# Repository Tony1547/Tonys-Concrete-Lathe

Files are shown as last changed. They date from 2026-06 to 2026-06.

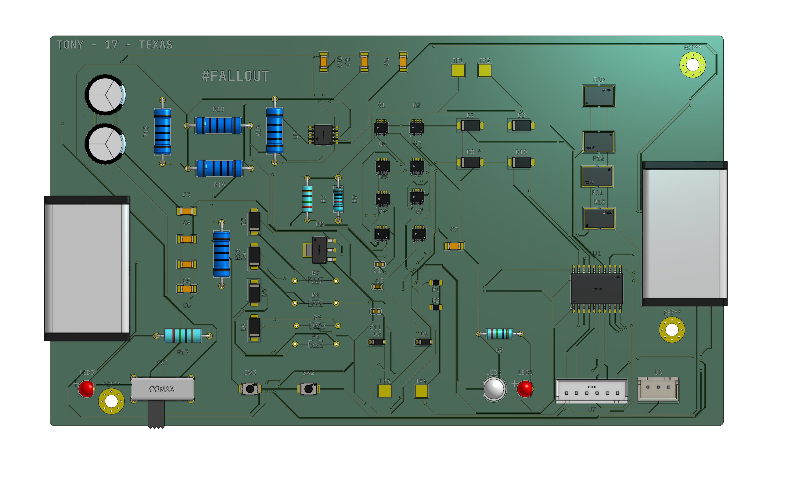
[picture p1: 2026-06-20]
images/LathePCB.png

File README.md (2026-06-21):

# Tonys-Concrete-Lathe #
Lathe but 3d prints &amp; concrete



Special thanks Mark Harris to for creating this open source design which I based my H-brdge motor driver off of, heres the link to his blog of his design and his git hub page:

- https://resources.altium.com/p/100a-12v-h-bridge-project

- https://github.com/issus

and another big thanks to Chris Borge for inspiring this project with his "I Printed A Better Lathe" video

- https://www.youtube.com/watch?v=6Js8erWbsDQ

---- 



This is the lathe I have been desingning for the past 2-ish months, I was initially inspired by Chris Borge a Youtuber who focuses on creating machines to help with his own personal projects and 3d-prints that are filled with concrete. Now, this is the second iteration design, not becuase I built a first lathe but because the first time I tried to put everything into CAD it all started to look like a toy and I thought I could do better, which I'm glad that I did. Which now leads to the vesion you see above and below this bar of text.

Something I initially struggled with was finding a way to connect all the parts toghether, in my initial design I tried to make each 3d printed part interlock with dove-tails but that soon became much more problematic than was needed. I solved this problem with allowing an open hole from part to part on the inside to connect all parts into this chamber that I hope keeps everything together once the concrete dries. 

For the reason that I built this project, I want to have better manufacturing capabilities at home, and having a machine that allows me to focus on one type of part (being conical and cylindrical parts) I think will allow me to have better projects in the future.

Journal: https://fallout.hackclub.com/projects/1831



# Assembly
Hi! if you're reading this, your either reading to review, see whats going on, or interested in building this project yourself.

- The first step in creating the lathe is set up, make sure you have all hardware, bearings, belt &amp; pulley's, 3d prints, PCB, concrete, and extrusion material on hand

- Make sure to use heated inserts before this next step and to cover anny holes which may clog with concrete with tape.

- The next step is is to assemble the base, head stock, and upper walls seperately, glue them with each other inside those groups and let it rest (you may want to put the hardware, extrusions, and linear slide in for the base before glueing), after the glue is done drying, you may start off by pouring concrete into the base.

- After concrete has been poured into the base (process can change depending on the part) you can now assemble and put-in the top of the lathe wall and headstock and fill those with conctete as well, if you can find a power tool to vibrate the lathe to allow air bubbles to escape then use that as well too.

-After allowing the concrete to dry, you may add on the tool carriage and screw on the PCB to to the lathe, make sure to wire and test and you should have a functional lathe!

Remember when using the lathe, the part should be spining to where it's coming down onto the tool and not the other way around.

Currently the lathe is run by either two buttons on the back for foward/revevrse but the option for external control was also given, so with an off board micro controller you could be very exact with how you want this thing to spin. (I plan to use an off board MCU when possible)





Onshape: https://cad.onshape.com/documents/8fec9f06f8e21e4e1cabcead/w/11b83efad18e13bc0ea2df61/e/2ea9e03e0bad05dbdf986923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

# BOM

Google Sheet: https://docs.google.com/spreadsheets/d/1Rf3SECQ2E7oCPYBzGCeOMEVJCDXd7yVN8Rsrsj5uyMo/edit?usp=sharing 

| Index | Vendor | Description | Quantity | Unit Price($) | Extended Price($) | Product Link | | | | | | | |
|---|---|---|---|---|---|---|---|---|-----|---|---|---|---|
| 1 | Ali Express | 5x13x4mm Flanged Bearing | 10 | $0.51 | $5.06 | https://www.aliexpress.us/item/3256803908686248.html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 | | | | | | | |
| 2 | Ali Express | 140T GT2 10mm belt | 1 | $3.78 | $3.78 | https://www.aliexpress.us/item/3256806906134014.html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 | | | | | | | |
| 3 | Ali Express | ER25 8mm Collet | 1 | $6.25 | $6.25 | https://www.aliexpress.us/item/2255800773550976.html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 | | | | | | | |
| 4 | Ali Express | 50mm Chuck | 1 | $20.01 | $20.01 | https://www.aliexpress.us/item/3256809251348831.html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 | | | | | | | |
| 5 | Ali Express | 30T + 60T Pulley's | 2 | $9.47 | $18.94 | https://www.aliexpress.us/item/3256805897449052.html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 | | | | | | | |
| 6 | Ali Express | 20x47x19.25 Tapered Roller Bearing | 2 | $3.59 | $7.18 | https://www.aliexpress.us/item/3256802472132854.html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 | | | | | | | |
| 7 | Ali Express | C20-ER25-150L Spindle | 1 | $15.84 | $15.84 | https://www.aliexpress.us/item/3256801168631119.html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 | | | | | | | |
| 8 | Tnutz | 2020 Extrusion | 2 | $1.33 | $2.66 | https://www.tnutz.com/product/exm-2020/?attribute_pa_length-in=12&attribute_pa_fractional-length=0-000 | | | | | | | |
| 9 | Tnutz | Tapped 2020 Extrusion | 2 | $0.77 | $1.54 | https://www.tnutz.com/product/exm-2020/?attribute_pa_length-in=3&attribute_pa_fractional-length=0-938-15-16 | | | | | | | |
| 10 | Tnutz | M3 T-Nut | 40 | $0.40 | $16.00 | https://www.tnutz.com/product/st-020/?attribute_pa_thread-size=m3-x-0-5 | | | | | | | |
| 11 | Grainger | 1M M4 Threaded Rod | 1 | $2.35 | $2.35 | https://www.grainger.com/product/Fully-Threaded-Rod-M4x0-70-25DM24 | | | | | | | |
| 12 | Grainger | M4 Nuts | 100 | $0.03 | $2.94 | https://www.grainger.com/product/Hex-Nut-Std-Hex-6CA71 | | | | | | | |
| 13 | Amazon | M3 Nuts | 150 | $0.03 | $4.99 | https://www.amazon.com/gp/product/B08N68W9SP/ref=ox_sc_act_title_1?smid=A2BPIUS9TNF8L5&psc=1 | | | | | | | |
| 14 | Amazon | 2 Part Epoxy | 1 | $5.97 | $5.97 | https://www.amazon.com/gp/product/B001Z3C3AG/ref=ox_sc_act_title_2?smid=ATVPDKIKX0DER&psc=1 | | | | | | | |
| 15 | Amazon | M3 Brass Inserts | 100 | $0.05 | $4.99 | https://www.amazon.com/gp/product/B0FM45X5TD/ref=ox_sc_act_title_3?smid=AIMQC13A5VC4X&psc=1 | | | | | | | |
| 16 | Amazon | M4 Brass Inserts | 60 | $0.08 | $4.83 | https://www.amazon.com/gp/product/B0DFWVT6XT/ref=ox_sc_act_title_4?smid=A3FX0IVQQTIB98&psc=1 | | | | | | | |
| 17 | Amazon | M3x10mm Screws | 120 | $0.03 | $3.79 | https://www.amazon.com/gp/product/B0F7LKRV5G/ref=ox_sc_act_title_5?smid=A2W3XYA7BVZZ2U&psc=1 | | | | | | | |
| 18 | Amazon | M3x25mm Screws | 40 | $0.16 | $6.39 | https://www.amazon.com/gp/product/B08R8J3175/ref=ox_sc_act_title_6?smid=A2XHUR0CG3X852&psc=1 | | | | | | | |
| 19 | Amazon | M3x22mm Screws | 50 | $0.13 | $6.29 | https://www.amazon.com/gp/product/B0FLYG7WZ7/ref=ox_sc_act_title_7?smid=A2SQCOYQC9C41K&psc=1 | | | | | | | |
| 20 | REV | #10-32 Socket head Screw | 50 | $0.11 | $5.50 | https://www.revrobotics.com/10-32-Socket-Head-Screws/ | | | | | | | |
| 21 | AndyMark | Cim Motor | 1 | $43.00 | $43.00 | https://andymark.com/products/2-5-in-cim-motor?variant=44497393680556 | | | | | | | |
| 22 | Ali Express | MGN9 300mm rail | 1 | $16.77 | $16.77 | https://www.aliexpress.us/item/2251832586981749.html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 | | | | | | | |
| 23 | Home Depot  | Concrete | 1 | $4.48 | $4.48 | https://www.homedepot.com/p/Quikrete-60-lb-Concrete-Mix-110160/100318478 | | | | | | | |
| | | | | Total = | $209.55 | | | | | | | | |
| | | | | | | | | | | | | | |
| Index | LCSC# | MPN | Manufacturer | Package | | Description | RoHS | Quantity | MOQ | Multiple | Unit Price($) | Extended Price($) | Product Link |
| 1 | C309795 | HIP4081AIBZT | RENESAS | SOIC-20-300mil | | Full-Bridge MOSFET 100mA 10ns 10ns 100mA SOIC-20-300mil Full Half-Bridge (H Bridge) Drivers RoHS | yes  | 1 | 1 | 1 | 4.3088 | 4.31 | https://www.lcsc.com/product-detail/C309795.html |
| 2 | C29936 | CL10B105KA8NNNC | Samsung Electro-Mechanics | 603 | | 1uF ±10% 25V Ceramic Capacitor X7R 0603 | yes  | 50 | 50  | 50 | 0.0219 | 1.1 | https://www.lcsc.com/product-detail/C29936.html |
| 3 | C22364900 | CDBA340L-G | Comchip | DO-214AC | | Diode 40V 3A Surface Mount DO-214AC | yes  | 8 | 1 | 1 | 1.1112 | 8.89 | https://www.lcsc.com/product-detail/C22364900.html |
| 4 | C18724377 | MF0S4FF200JA50 | UNI-ROYAL | Through Hole,D1.9xL3.3mm  | | 20Ω 250mW Metal Film Resistor ±50ppm/℃ ±1% Through Hole,D1.9xL3.3mm Through Hole Resistors RoHS | yes  | 50 | 50  | 50 | 0.005 | 0.25 | https://www.lcsc.com/product-detail/C18724377.html |
| 5 | C9807 | CL31A106KAHNNNE | Samsung Electro-Mechanics | 1206 | | 10uF ±10% 25V Ceramic Capacitor X5R 1206 | yes  | 10 | 10  | 10 | 0.0937 | 0.94 | https://www.lcsc.com/product-detail/C9807.html |
| 6 | C24497 | CL31B104KBCNNNC | Samsung Electro-Mechanics | 1206 | | 100nF ±10% 50V Ceramic Capacitor X7R 1206 | yes  | 20 | 20  | 20 | 0.019 | 0.38 | https://www.lcsc.com/product-detail/C24497.html |
| 7 | C553224 | PSMN1R5-25MLHX | Nexperia | SOT-1210 | | N-Channel 25V 150A 106W SOT-1210 | yes  | 8 | 1 | 1 | 3.6382 | 29.11 | https://www.lcsc.com/product-detail/C553224.html |
| 8 | C3454390 | MFR-25FBF52-2K2 | YAGEO | Through Hole,D2.4xL6.3mm  | | 2.2kΩ 250mW Metal Film Resistor ±100ppm/℃ ±1% Through Hole,D2.4xL6.3mm Through Hole Resistors RoHS | yes  | 50 | 50  | 50 | 0.0195 | 0.98 | https://www.lcsc.com/product-detail/C3454390.html  |
| 9 | C330747 | TJ-L3FYTGHKMCGSFLC7K-A5 | TOGIALED | Through Hole,D=3mm | | LED Indication - Discrete Through Hole,D=3mm | yes  | 20 | 20  | 20 | 0.0292 | 0.58 | https://www.lcsc.com/product-detail/C330747.html |
| 10 | C559114 | MHL5013UBDWT | MEIHUA | Through Hole,D=5mm | | Blue 470nm LED Indication - Discrete 3.2V Through Hole,D=5mm | yes  | 10 | 10  | 10 | 0.0523 | 0.52 | https://www.lcsc.com/product-detail/C559114.html |
| 11 | C61299 | CFR0W4J0103A50 | UNI-ROYAL | Through Hole,D2.2xL6.5mm  | | 10kΩ 250mW 250V Carbon Film Resistor ±450ppm/℃ ±5% Through Hole,D2.2xL6.5mm Through Hole Resistors RoHS | yes  | 50 | 50  | 50 | 0.0125 | 0.63 | https://www.lcsc.com/product-detail/C61299.html |
| 12 | C113892 | CC1206KKX7R0BB224 | YAGEO | 1206 | | 220nF ±10% 100V Ceramic Capacitor X7R 1206 | yes  | 20 | 20  | 20 | 0.0404 | 0.81 | https://www.lcsc.com/product-detail/C113892.html |
| 13 | C843877 | WSHP28182L000FEA | VISHAY | 2818 | | 2mΩ 10W ±1% ±200ppm/℃ 2818 Chip Resistor - Surface Mount RoHS | yes  | 4 | 1 | 1 | 2.3567 | 9.43 | https://www.lcsc.com/product-detail/C843877.html |
| 14 | C119483 | MF1W-1KΩ±1% T | CCO(Chian Chia Elec) | Through Hole,D4.5xL11.5mm | | 1kΩ 1W 350V Metal Film Resistor ±100ppm/℃ ±1% Through Hole,D4.5xL11.5mm Through Hole Resistors RoHS | yes  | 10 | 10  | 10 | 0.0496 | 0.5 | https://www.lcsc.com/product-detail/C119483.html |
| 15 | C707749 | KF88SA-16.0-2P | Cixi Kefa Elec | Through Hole,P=16mm | | 2 Position Barrier Block Connector 6~14 AWG 1000V 76A Through Hole | yes  | 2 | 1 | 1 | 0.8305 | 1.66 | https://www.lcsc.com/product-detail/C707749.html |
| 16 | C435835 | LDL1117S33R | ST | SOT-223-4 | | 3.3V Positive Fixed SOT-223-4 Voltage Regulators - Linear, Low Drop Out (LDO) Regulators RoHS | yes  | 5 | 5 | 5 | 0.2132 | 1.07 | https://www.lcsc.com/product-detail/C435835.html |
| 17 | C158012 | B2B-XH-A(LF)(SN) | JST | Through Hole,P=2.5mm | | Connector Header 2 position 2.5mm Pitch 3A Through Hole -25℃~+85℃ | yes  | 20 | 20  | 20 | 0.0405 | 0.81 | https://www.lcsc.com/product-detail/C158012.html |
| 18 | C144397 | B6B-XH-A(LF)(SN) | JST | Through Hole,P=2.5mm | | Connector Header 6 position 2.5mm Pitch 3A Through Hole -25℃~+85℃ | yes  | 5 | 5 | 5 | 0.0917 | 0.46 | https://www.lcsc.com/product-detail/C144397.html |
| 19 | C455280 | TS-1088R-02026 | XUNPU | SMD,4x3mm | | Tactile Switch SPST 2mm 3.9mm x 2.93mm Surface Mount | yes  | 10 | 10  | 10 | 0.0597 | 0.6 | https://www.lcsc.com/product-detail/C455280.html |
| | | | | | | | | | | | | Total = 63.42 | |
| Total = | $272.97 | | | | | | | | | | | | |

# PCB Schematic





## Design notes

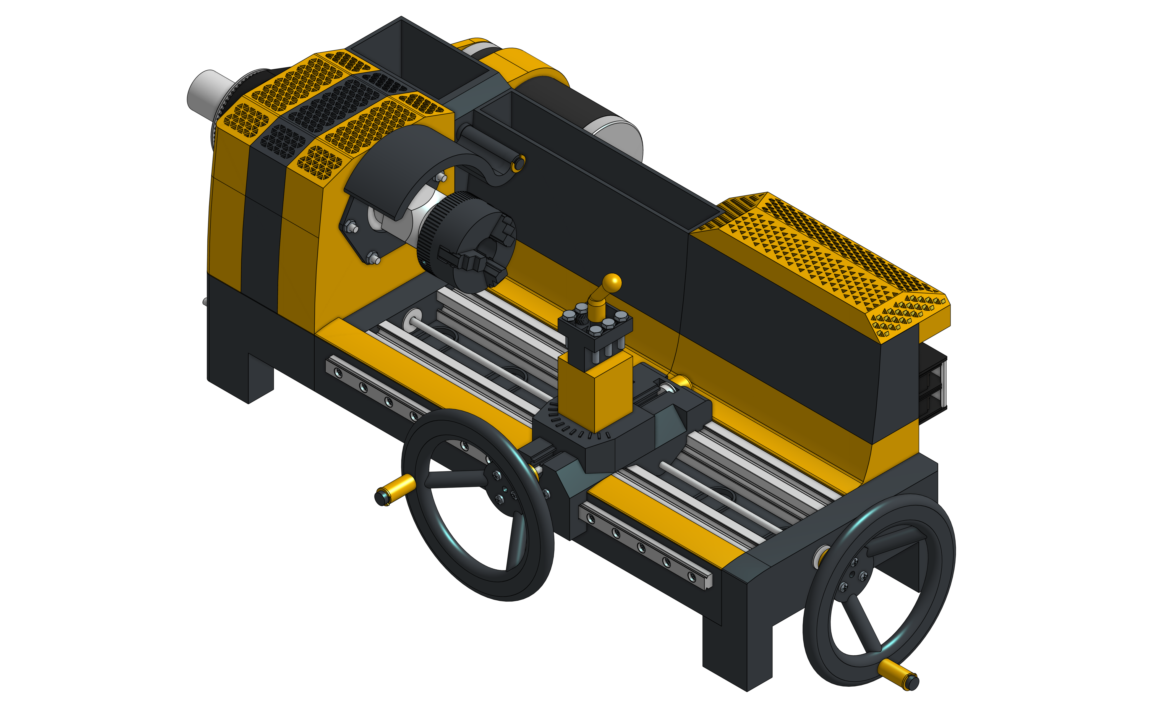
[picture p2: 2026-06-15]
images/Lathe V2.png

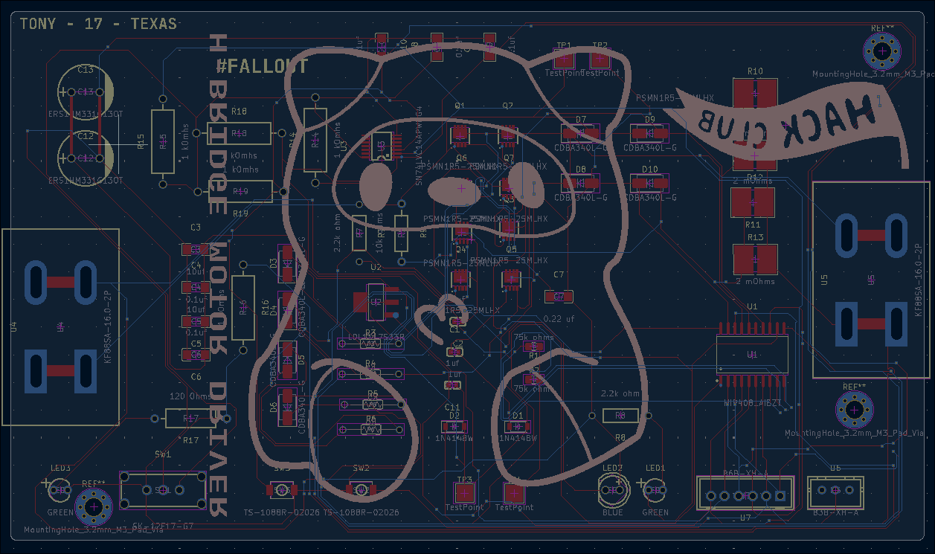
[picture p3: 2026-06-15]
images/2026-06-15-164054_hyprshot.png

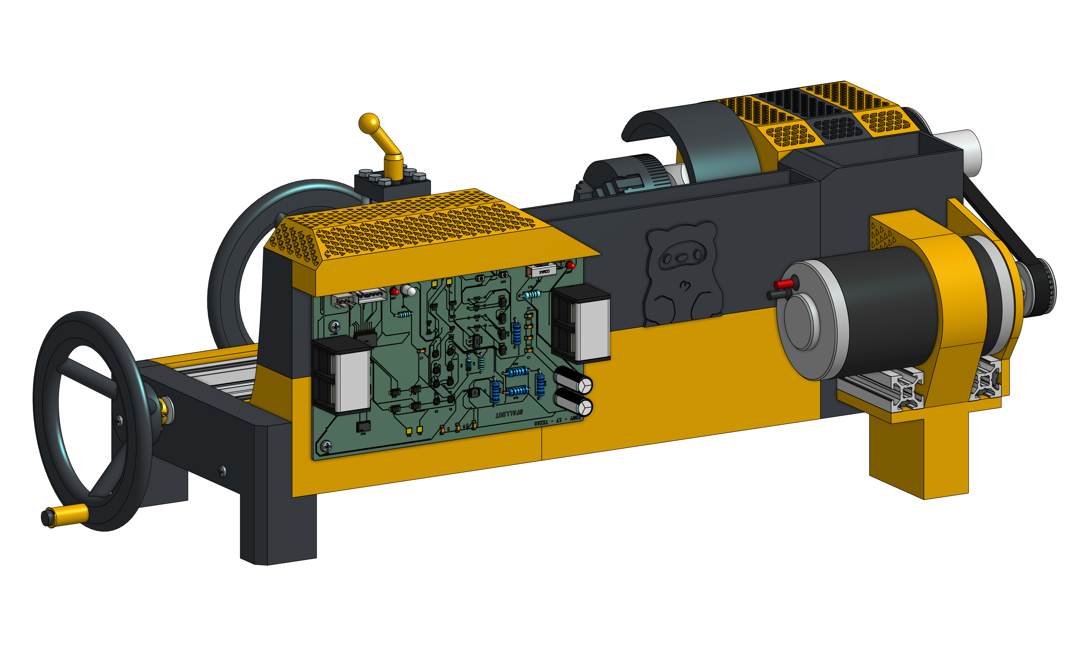
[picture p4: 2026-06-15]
images/Lathe V2 Back .png

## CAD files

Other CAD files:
step files/Lathe V2 full assembly.step
step files/3d printed parts/Lathe V2 - Tool Holder Base.step
step files/bearings/Lathe V2 - 25x52x19.2mm Bearing.step
step files/pcb/LathePCB 1 - Lathe PCB_silkscreen (244).step
step files/head stock/Lathe V2 - GT2 3mm 30 Tooth Custom Pulley.step
step files/3d printed parts/Lathe V2 - Head Stock Part 2.step
step files/bearings/Lathe V2 - 5x13x4mm Flanged Bearing.step
step files/head stock/Lathe V2 - Chuck.step
step files/linear rail/Lathe V2 - MGN9H - Carriage (19).step
step files/3d printed parts/Lathe V2 - Hand Wheel Turny Bit.step
step files/pcb/LathePCB 1 - SOIC-20_L12.8-W7.5-H2.7-LS10.3-P1.27 (10).step
step files/head stock/Lathe V2 - Chuck Gripper.step
step files/linear rail/Lathe V2 - Carriage MGN9H (1).step
step files/pcb/LathePCB 1 - Lathe PCB_copper (16).step
step files/linear rail/Lathe V2 - MGN9 - 300mm.step
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

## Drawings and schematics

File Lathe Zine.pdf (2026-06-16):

# TONY’S LATHE

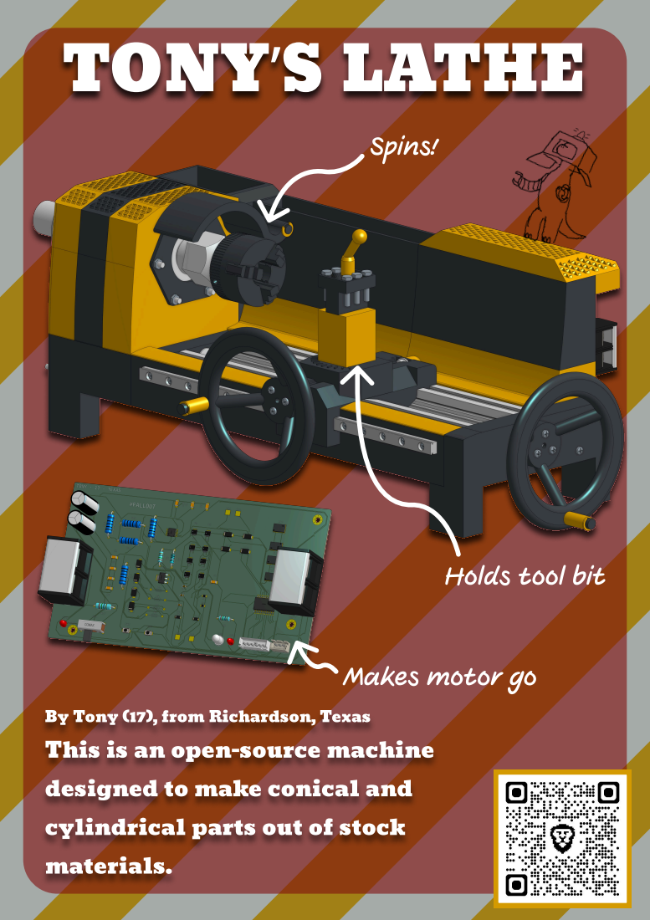
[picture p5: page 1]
Spins!

Holds tool bit

Makes motor go

By Tony (17), from Richardson, Texas
This is an open-source machine
designed to make conical and
cylindrical parts out of stock
materials.

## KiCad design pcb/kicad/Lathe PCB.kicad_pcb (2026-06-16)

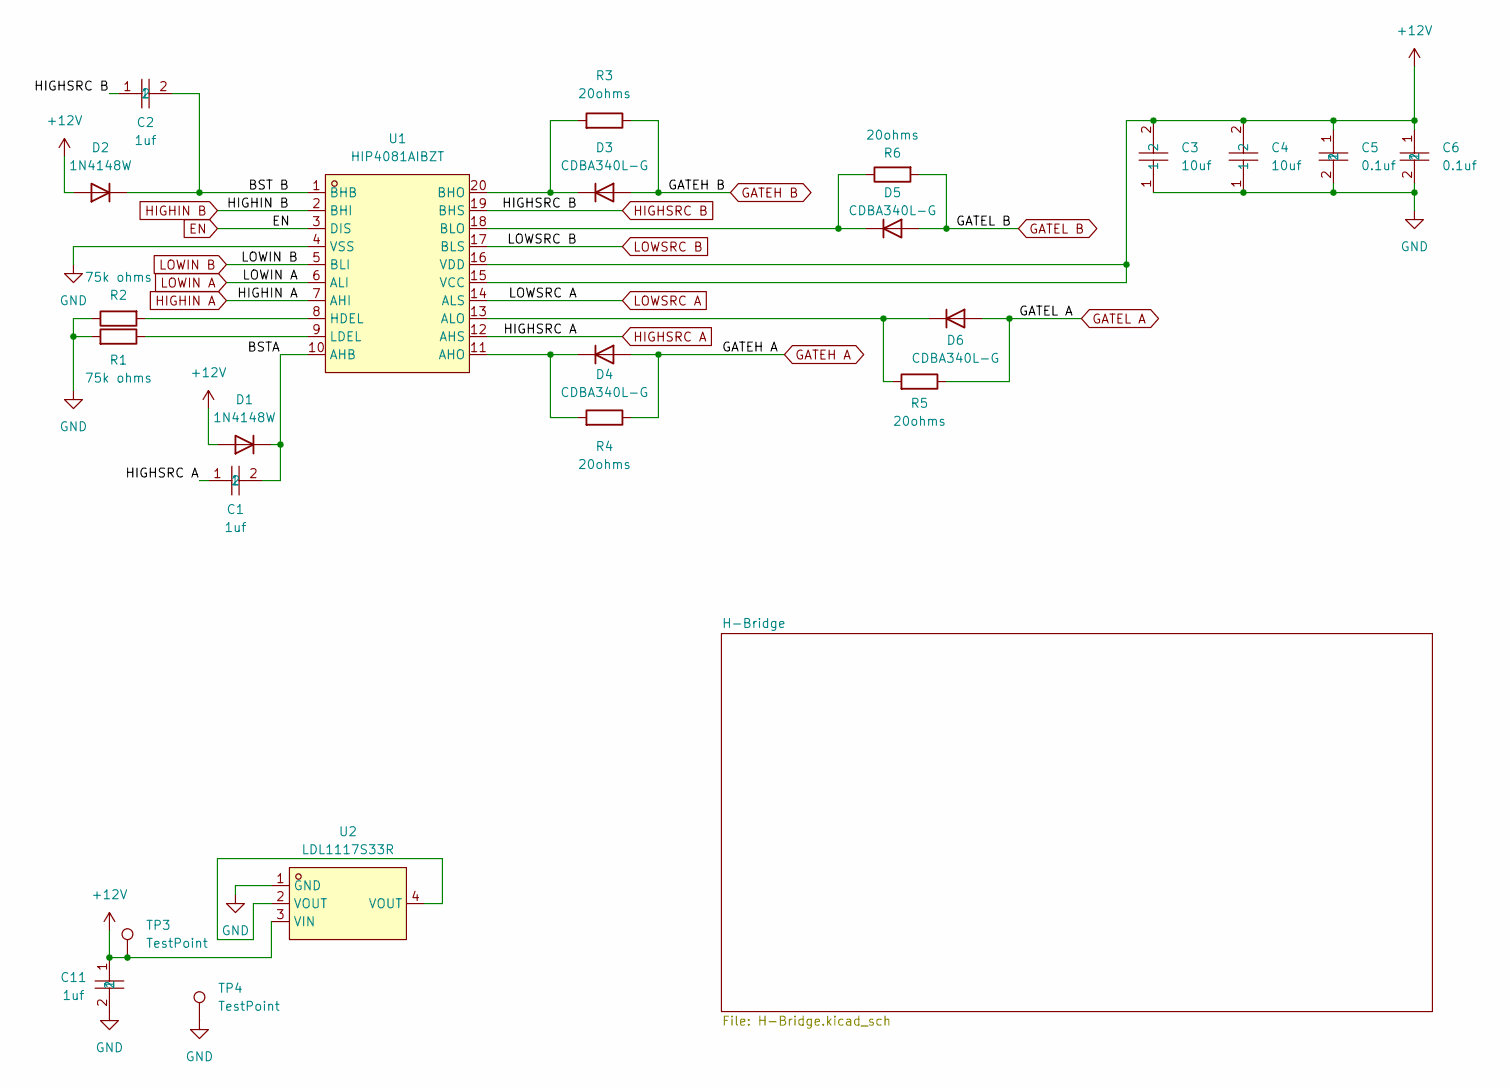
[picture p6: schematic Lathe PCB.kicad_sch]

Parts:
C1, C2, C11: 1uf; C0603; MPN CL10B105KA8NNNC; LCSC Part C29936
C3, C4: 10uf; C1206; MPN CL31A106KAHNNNE; LCSC Part C9807
C5, C6: 0.1uf; C1206; MPN CL31B104KBCNNNC; LCSC Part C24497
D1, D2: 1N4148W; D_SOD-123
D3, D4, D5, D6: CDBA340L-G; D_SMA
R1, R2: 75k ohms; R_0805_2012Metric_Pad1.20x1.40mm_HandSolder
R3, R4, R5, R6: 20ohms; R_Axial_DIN0204_L3.6mm_D1.6mm_P10.16mm_Horizontal
TP3, TP4: TestPoint; TestPoint_Pad_3.0x3.0mm
U1: HIP4081AIBZT; SOIC-20_L13.0-W7.6-P1.27-LS10.3-BL; MPN HIP4081AIBZT; LCSC Part C309795
U2: LDL1117S33R; SOT-223-4_L6.5-W3.5-P2.30-LS7.0-BR; MPN LDL1117S33R; LCSC Part C435835

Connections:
+12V: C3.2, C4.2, C5.1, C6.1, C11.1, D1.2 (A), D2.2 (A), TP3.1 (1_1), U1.15 (VCC), U1.16 (VDD), U2.3 (VIN); also elsewhere on the board
/BST B: C2.2, D2.1 (K), U1.1 (BHB)
/BSTA: C1.2, D1.1 (K), U1.10 (AHB)
EN: U1.3 (DIS); also elsewhere on the board
GATEH A: D4.2 (A), R4.2; also elsewhere on the board
GATEH B: D3.2 (A), R3.2; also elsewhere on the board
GATEL A: D6.2 (A), R5.2; also elsewhere on the board
GATEL B: D5.2 (A), R6.1; also elsewhere on the board
GND: C3.1, C4.1, C5.2, C6.2, C11.2, R1.1, R2.2, TP4.1 (1_1), U1.4 (VSS), U2.1 (GND); also elsewhere on the board
HIGHIN A: U1.7 (AHI); also elsewhere on the board
HIGHIN B: U1.2 (BHI); also elsewhere on the board
HIGHSRC A: C1.1, U1.12 (AHS); also elsewhere on the board
HIGHSRC B: C2.1, U1.19 (BHS); also elsewhere on the board
LOWIN A: U1.6 (ALI); also elsewhere on the board
LOWIN B: U1.5 (BLI); also elsewhere on the board
LOWSRC A: U1.14 (ALS); also elsewhere on the board
LOWSRC B: U1.17 (BLS); also elsewhere on the board
unnamed: D3.1 (K), R3.1, U1.20 (BHO)
unnamed: D4.1 (K), R4.1, U1.11 (AHO)
unnamed: D5.1 (K), R6.2, U1.18 (BLO)
unnamed: D6.1 (K), R5.1, U1.13 (ALO)
unnamed: R2.1, U1.8 (HDEL)
unnamed: R1.2, U1.9 (LDEL)
unnamed: U2.2 (VOUT), U2.4 (VOUT)

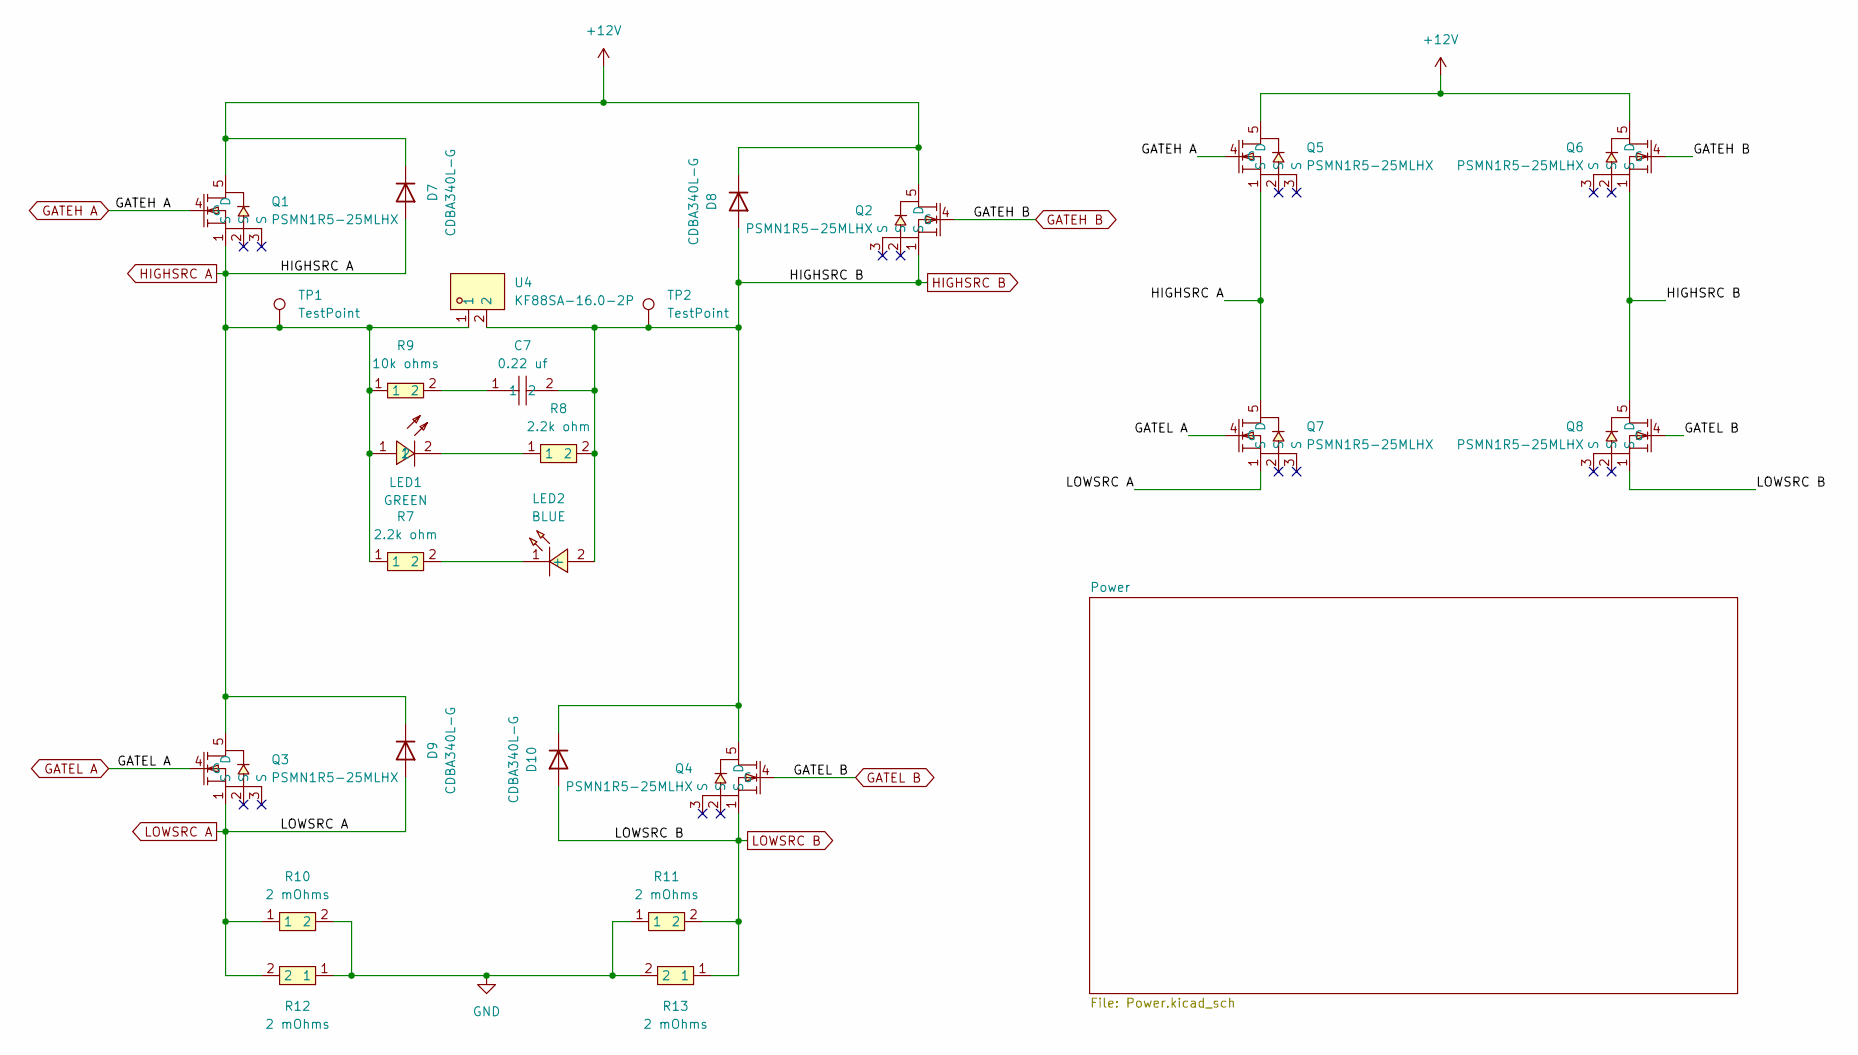
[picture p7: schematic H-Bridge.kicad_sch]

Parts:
C7: 0.22 uf; C1206; MPN CC1206KKX7R0BB224; LCSC Part C113892
D7, D8, D9, D10: CDBA340L-G; D_SMA
LED1: GREEN; LED-TH_BD3.8-P2.54-FD; MPN TJ-L3FYTGHKMCGSFLC7K-A5; LCSC Part C330747
LED2: BLUE; LED-TH_BD5.0-P2.54-L-RD_WHITE; MPN MHL5013UBDWT; LCSC Part C559114
Q1, Q2, Q3, Q4, Q5, Q6, Q7, Q8: PSMN1R5-25MLHX; SOT-1210_L3.3-W2.6-P0.65-LS3.3-BL; MPN PSMN1R5-25MLHX; LCSC Part C553224
R7, R8: 2.2k ohm; RES-TH_BD2.4-L6.3-P10.30-D0.6; MPN MFR-25FBF52-2K2; LCSC Part C3454390
R9: 10k ohms; RES-TH_BD2.2-L6.5-P10.50-D0.6; MPN CFR0W4J0103A50; LCSC Part C61299
R10, R11, R12, R13: 2 mOhms; R2818; MPN WSHP28182L000FEA; LCSC Part C843877
TP1, TP2: TestPoint; TestPoint_Pad_3.0x3.0mm
U4: KF88SA-16.0-2P; CONN-TH_KF88SA-16.0-2P; MPN KF88SA-16.0-2P; LCSC Part C707749

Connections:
+12V: D7.1 (K), D8.1 (K), Q1.5 (D), Q2.5 (D), Q5.5 (D), Q6.5 (D); also elsewhere on the board
GATEH A: Q1.4 (G), Q5.4 (G); also elsewhere on the board
GATEH B: Q2.4 (G), Q6.4 (G); also elsewhere on the board
GATEL A: Q3.4 (G), Q7.4 (G); also elsewhere on the board
GATEL B: Q4.4 (G), Q8.4 (G); also elsewhere on the board
GND: R10.2, R11.1, R12.1, R13.2; also elsewhere on the board
HIGHSRC A: D7.2 (A), D9.1 (K), LED1.1, Q1.1 (S), Q3.5 (D), Q5.1 (S), Q7.5 (D), R7.1, R9.1, TP1.1 (1_1), U4.1; also elsewhere on the board
HIGHSRC B: C7.2, D8.2 (A), D10.1 (K), LED2.2 (+), Q2.1 (S), Q4.5 (D), Q6.1 (S), Q8.5 (D), R8.2, TP2.1 (1_1), U4.2; also elsewhere on the board
LOWSRC A: D9.2 (A), Q3.1 (S), Q7.1 (S), R10.1, R12.2; also elsewhere on the board
LOWSRC B: D10.2 (A), Q4.1 (S), Q8.1 (S), R11.2, R13.1; also elsewhere on the board
unnamed: C7.1, R9.2
unnamed: LED1.2, R8.1
unnamed: LED2.1 (-), R7.2

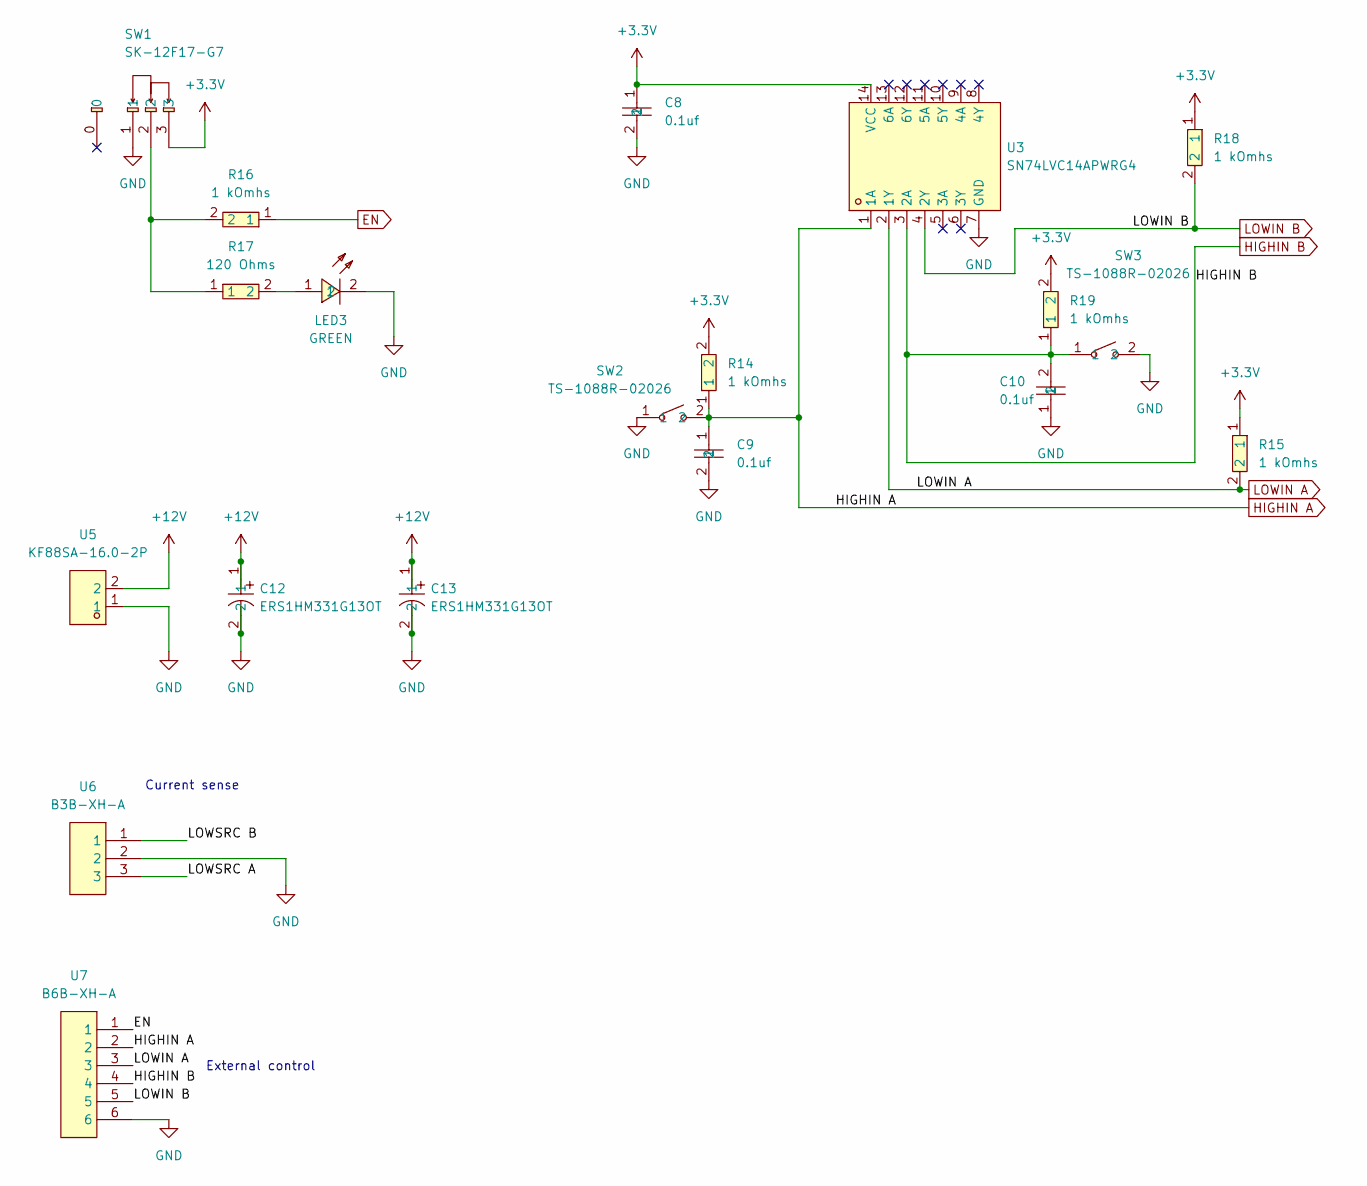
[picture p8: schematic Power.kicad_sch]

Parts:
C8, C9, C10: 0.1uf; C1206; MPN CL31B104KBCNNNC; LCSC Part C24497
C12, C13: ERS1HM331G13OT; CAP-TH_BD10.0-P5.00-D0.6-FD; MPN ERS1HM331G13OT; LCSC Part C2758058
LED3: GREEN; LED-TH_BD3.8-P2.54-FD; MPN TJ-L3FYTGHKMCGSFLC7K-A5; LCSC Part C330747
R14, R15, R16, R18, R19: 1 kOmhs; RES-TH_BD4.0-L11.5-P15.50-D0.7; MPN MF1W-1KΩ±1% T; LCSC Part C119483
R17: 120 Ohms; RES-TH_BD3.3-L9.0-P13.00-D0.6; MPN MF1/2W-120Ω±1% T; LCSC Part C119408
SW1: SK-12F17-G7; SW-TH_SK-12F17-G7; MPN SK-12F17-G7; LCSC Part C221971
SW2, SW3: TS-1088R-02026; SW-SMD_L3.9-W3.0-P4.45; MPN TS-1088R-02026; LCSC Part C455280
U3: SN74LVC14APWRG4; TSSOP-14_L5.0-W4.4-P0.65-LS6.4-BL; MPN SN74LVC14APWR; LCSC Part C7663
U5: KF88SA-16.0-2P; CONN-TH_KF88SA-16.0-2P; MPN KF88SA-16.0-2P; LCSC Part C707749
U6: B3B-XH-A; CONN-TH_3P-P2.50_A2501WV2-3P; MPN B3B-XH-A(LF)(SN); LCSC Part C144394
U7: B6B-XH-A; CONN-TH_6P-P2.50_B6B-XH-A-LF-SN; MPN B6B-XH-A(LF)(SN); LCSC Part C144397

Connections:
+3.3V: C8.1, R14.2, R15.1, R18.1, R19.2, SW1.3, U3.14 (VCC)
+12V: C12.1, C13.1, U5.2; also elsewhere on the board
/H-Bridge/Power/LOWSRC A: U6.3
/H-Bridge/Power/LOWSRC B: U6.1
EN: R16.1, U7.1; also elsewhere on the board
GND: C8.2, C9.2, C10.1, C12.2, C13.2, LED3.2, SW1.1, SW2.1, SW3.2, U3.7 (GND), U5.1, U6.2, U7.6; also elsewhere on the board
HIGHIN A: C9.1, R14.1, SW2.2, U3.1 (1A), U7.2; also elsewhere on the board
HIGHIN B: C10.2, R19.1, SW3.1, U3.3 (2A), U7.4; also elsewhere on the board
LOWIN A: R15.2, U3.2 (1Y), U7.3; also elsewhere on the board
LOWIN B: R18.2, U3.4 (2Y), U7.5; also elsewhere on the board
unnamed: LED3.1, R17.2
unnamed: R16.2, R17.1, SW1.2

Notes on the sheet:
External control
Current sense

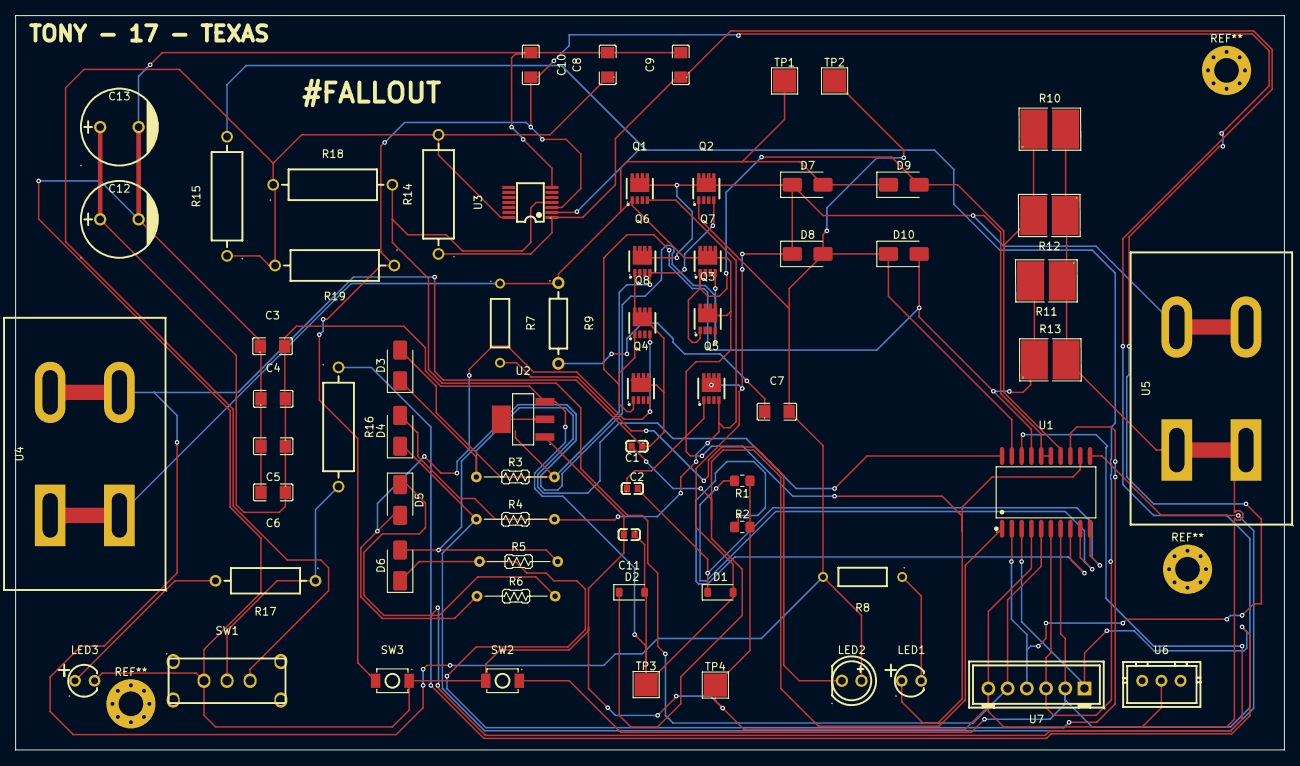
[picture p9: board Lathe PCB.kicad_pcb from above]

Board: 2 copper layers, 165.0 x 95.5 mm, 67 parts (0 on the bottom side), 30 nets.

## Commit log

2026-06-15 Gerber and Step files added
    [Lathe PCB-B_Cu.gbr, Lathe PCB-B_Mask.gbr, Lathe PCB-B_Paste.gbr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]
2026-06-16 organize stl files
    [Lathe V2 - #10-32 x 3-8- L BHCS (Steel, Black Oxide).stl, Lathe V2 - 140 Tooth x 9mm GT2 3mm Belt.stl, Lathe V2 - 2020 Extrusion (1).stl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]
2026-06-16 rename folders
    [Lathe PCB-B_Cu.gbr, Lathe PCB-B_Mask.gbr, Lathe PCB-B_Paste.gbr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]
2026-06-16 added kicad files
    [H-Bridge.kicad_sch, Lathe PCB.kicad_pcb, Lathe PCB.kicad_sch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]
2026-06-16 Add Lathe BOM.csv
    [Lathe BOM.csv]
2026-06-20 updated organization
    [Lathe V2 - Back Left Wall Base.stl, Lathe V2 - Back Left Wall.stl, Lathe V2 - Back Right Wall Base.stl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]
2026-06-20 Git LFS
    [Lathe V2 - #10-32 x 3-8- L BHCS (Steel, Black Oxide).stl, Lathe V2 - 140 Tooth x 9mm GT2 3mm Belt.stl, Lathe V2 - 2020 Extrusion (1).stl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]
2026-06-20 update bom
    [Lathe BOM.csv]
2026-06-21 rename for clarity
    [Lathe V2 full assembly.stl]
2026-06-21 rename for clarity
    stl folder
    [Lathe V2 - #10-32 x 3-8- L BHCS (Steel, Black Oxide).stl, Lathe V2 - 140 Tooth x 9mm GT2 3mm Belt.stl, Lathe V2 - 2020 Extrusion (1).stl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]
2026-06-23 replaced stl with step
    [Lathe V2 - #10-32 x 3-8- L BHCS (Steel, Black Oxide) (1).step, Lathe V2 - #10-32 x 3-8- L BHCS (Steel, Black Oxide).step, Lathe V2 - #10-32 x 3-8- L BHCS (Stee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]
